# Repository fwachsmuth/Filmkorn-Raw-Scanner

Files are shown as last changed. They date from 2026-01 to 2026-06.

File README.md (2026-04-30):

# Filmkorn Raw-Scanner
## An affordable 12‑Bit 4K Motion Picture Film Scanner

Another DIY film scanner?  
Yes, but this one is different: the Filmkorn Raw Scanner is an open‑source project that enables digitizing small‑gauge films at breathtaking quality for a very low price. The project began in 2020 after a bet on the German [Filmvorführerforum](https://www.filmvorfuehrer.de/topic/31851-challenge-framescanner-f%C3%BCr-350%E2%82%AC-bauen/), when the infamous but similarly priced “Wolverine” film scanner from China (aka Somikon, aka Winait, aka Kodak, aka Hammacher‑Schlemmer) turned out to be an irredeemable film‑scratching disaster: Is it even possible to build a truly high‑quality scanner for under €500?

Yes, it is. Now anyone can build a scanner that digitizes their films gently and in fantastic quality.

## Introduction Video
Filmkorn Raw Scanner – demo video (https://www.youtube.com/watch?v=_LFE7quf9N0)

*(Click to play on Youtube)*

## Links
- You find extensive documentation on the [Project Wiki](https://github.com/fwachsmuth/Filmkorn-Raw-Scanner/wiki) (English and German)
- [Example Demo Video](https://www.youtube.com/watch?v=y674Rku_erA) (compressed, since Youtube)
- [Shop 🛒](https://lectronz.com/products/filmkorn-scanner-controller-board) to get a ready-made and populated Controller PCB and optionally some special accessories
- The latest [Image file](https://github.com/fwachsmuth/Filmkorn-Raw-Scanner/releases) for the Raspberry Pi
- Got your Scanner? [Getting Started](https://github.com/fwachsmuth/Filmkorn-Raw-Scanner/wiki/3.-User-Guide-EN)

**Special offer: Send me detailed photos and a description of converting another projector (Bauer, Eumig, whatever) for publication on this page, and I’ll refund the cost of the Scan‑Controller on request!**

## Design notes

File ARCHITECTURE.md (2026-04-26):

# Architecture

## System Roles

### Raspberry Pi — Camera and Brain

The Raspi is the central coordinator. It runs `scanner.py`, a Python application that:

- Controls the Pi HQ Camera (IMX477) via **picamera2**, capturing 12-bit DNG raw frames at up to 4K (4056×3040) or 2K (2028×1520).
- Drives an **HDMI overlay UI** (PIL/ImageDraw rendered to DRM framebuffer via tty1) for live preview and status display.
- Communicates with the Controller PCB via **I2C** (bus 1, address 0x2A), and polling it during scanning.
- Manages **file sync**: captured frames land in a RAM disk (`/mnt/ramdisk`), from which lsyncd moves them to the host Mac over Ethernet or to a local USB drive.
- Handles **OTA firmware updates**, SSH pairing, WiFi captive portal for network setup, and sleep/wake power management.

### Controller PCB — Hardware Interface

The PCB is built around an **ATmega328P** (Pretty much an Arduino Pro Mini at 3.3V and 8 MHz). It owns everything physical:

- **Film transport motor** — PWM-driven forward/reverse with a calibrated minimum duty cycle to guarantee movement from rest.
- **Eye sensor** (IR on GPIO2) — watches the main shaft and detectes a finished revolution via hardware interrupt (`stopMotorISR`). The ISR stops the motor and sets `CMD_SHOOT_RAW` for the next I2C poll from the Pi.
- **Film-end sensor** (GPIO3) — detects when the film strip runs out and stops scanning.
- **Lamp and fan** control (GPIO9, GPIO8).
- **Buttons and potentiometers** (analog pins A0–A3, A6) — navigation buttons, step/continuous speed knobs, exposure pot.
- **Board revision detection** (A7) — voltage divider that identifies PCB revision at runtime.

The firmware acts as an I2C slave. The Pi polls it; the controller queues one command at a time in `nextPiCmd` and returns it on the next `Wire.onRequest()` call.

### Host Computer — Optional Storage (macOS)

The host Mac is entirely optional. When paired over Ethernet:

- Receives DNG files from the Raspi in real time via **lsyncd + rsync** (rsync 3.x, SSH over eth0 only).
- Source files on the RAM disk are deleted after a successful transfer (`--remove-source-files`), keeping RAM usage flat.
- Hosts the **pairing scripts** (`host-computer/`) that establish SSH trust, configure file sync paths, and install the Remote Login prerequisite.

Without a paired host, scans go to a USB drive mounted at `/mnt/usb`.

---

## systemd Services

| Service | Type | Role |
|---|---|---|
| `filmkorn-ramdisk` | oneshot | Creates and mounts the RAM disk at `/mnt/ramdisk`; must be running before the scanner starts |
| `filmkorn-scanner` | simple | Main Python application — camera, I2C, UI, file routing. Restarts on failure. Requires `filmkorn-ramdisk` |
| `filmkorn-lsyncd` | simple | Runs lsyncd to sync `/mnt/ramdisk/` → host Mac (net) or `/mnt/usb/` (local). Config symlinked via `lsyncd.active.conf` |
| `filmkorn-firstboot` | oneshot | One-time setup on first boot: SSH host key generation, swap config, rootfs expansion |
| `filmkorn-sleep` | oneshot | Triggered by scanner.py to power down non-essential hardware for idle sleep |
| `filmkorn-wake` | oneshot | Triggered on wake to restore hardware state |
| `filmkorn-otp-schedule` | oneshot | Sets a timer to revoke the WiFi pairing OTP after its expiry window |
| `usb-mount-largest@` | oneshot | Udev-triggered: mounts the largest partition of a plugged-in USB drive to `/mnt/usb` |
| `usb-umount@` | oneshot | Udev-triggered: unmounts and syncs the USB drive on removal |

---

## Scanning Flow

```mermaid
sequenceDiagram
    participant User
    participant Controller as Controller PCB<br/>(ATmega328P)
    participant Pi as Raspberry Pi<br/>(scanner.py)
    participant Cam as Pi HQ Camera<br/>(picamera2)
    participant Disk as Storage<br/>(RAM disk → host/USB)

    User->>Controller: Press SCAN button
    Controller->>Pi: I2C poll → CMD_START_SCAN
    Pi->>Pi: Check storage available
    Pi->>Controller: I2C → CMD_READY
    Controller->>Controller: Enable lamp + fan

    loop For each frame
        Controller->>Controller: motorFWD1()<br/>advance film one frame
        Note over Controller: Eye sensor (IR) fires<br/>stopMotorISR() on FALLING edge
        Controller->>Controller: Stop motor<br/>nextPiCmd = CMD_SHOOT_RAW
        Controller->>Pi: I2C poll → CMD_SHOOT_RAW
        Pi->>Cam: Drain stale buffered frames<br/>(transport-era frames)
        Cam->>Pi: Capture DNG (12-bit raw)
        Pi->>Disk: Write DNG to /mnt/ramdisk/
        Pi->>Controller: I2C → CMD_READY
    end

    Note over Disk: lsyncd watches /mnt/ramdisk/<br/>rsync to host or USB<br/>deletes source after transfer

    alt Film end detected
        Controller->>Controller: Film-end sensor triggers<br/>stop scanning
        Controller->>Pi: I2C poll → CMD_STOP_SCAN
        Pi->>Pi: Wait for RAM disk to drain<br/>then show idle screen
    else User stops
        User->>Controller: Press STOP
        Controller->>Pi: I2C poll → CMD_STOP_SCAN
    end
```

### Key timing detail

The camera runs continuously in a ring buffer (`buffer_count=4`). When `CMD_SHOOT_RAW` arrives, the film has just stopped but the buffer still holds frames captured while it was moving ("transport-era frames"). `scanner.py` discards these before saving — using either a frame-count strategy (fast shutters) or a fixed settle + shutter-duration wait (slow shutters > 1/100 s). A user-adjustable "capture latency" setting controls how many additional frames are discarded as a safety margin.

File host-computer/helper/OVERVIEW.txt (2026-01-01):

        Host Computer                                   Raspberry Pi

┌──────────────────────────────────────┐
│ install_remote_scanning.sh           │
│ - installs Homebrew + rsync          │
│ - enables Remote Login               │
│ - touches .scanner_installed         │
└──────────────────┬───────────────────┘
                   │
                   ▼
┌──────────────────────────────────────┐
│ helper/pair.sh                       │
│ - creates and installs an ssh key    │
│ - configures raspi keys              │          ┌────────────────────────────────┐
│ - ensures destination path is set    ├─────────►│ pairing/update-destination.sh  │
└──────────────────────────────────────┘  calls   │ (via pair.sh)                  │
                   │                              │ - creates lsyncd-to-host.conf  │
                   │ if no scan                   │ - writes .scan_destination     │
                   │ destination                  │ - validates host/path/rsync    │
                   │ defined yet                  └────────────────────────────────┘
                   │
                   ▼
┌──────────────────────────────────────┐          ┌────────────────────────────────┐
│ helper/set_scan_destination.sh       │          │ pairing/update-destination.sh  │
│ - updates local .scan_destination    ├─────────►│ (via set_scan_destination.sh)  │
│ - calls update-destination           │  calls   │ - creates lsyncd-to-host.conf  │
└──────────────────────────────────────┘          │ - writes .scan_destination     │
                                                  │ - validates host/path/rsync    │
                                                  └────────────────────────────────┘

┌──────────────────────────────────────┐          ┌────────────────────────────────┐
│ helper/unpair.sh                     │          │ pairing/unpair-from-client.sh  │
│ - removes ssh keys and allowances    ├─────────►│ - removes ssh keys and         │
│                                      │  calls   │   makes the host computer      │
└──────────────────────────────────────┘          │   unknown                      │
                                                  └────────────────────────────────┘

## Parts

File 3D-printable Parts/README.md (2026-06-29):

## (Optional) 3D parts for lucky owners of a 3D printer

This directory contains some 3D printable parts for convenience and beauty, contributed by others. Thanks a ton for this, feel free to send any other parts you might create (or just raise a PR).

### Noris specific parts

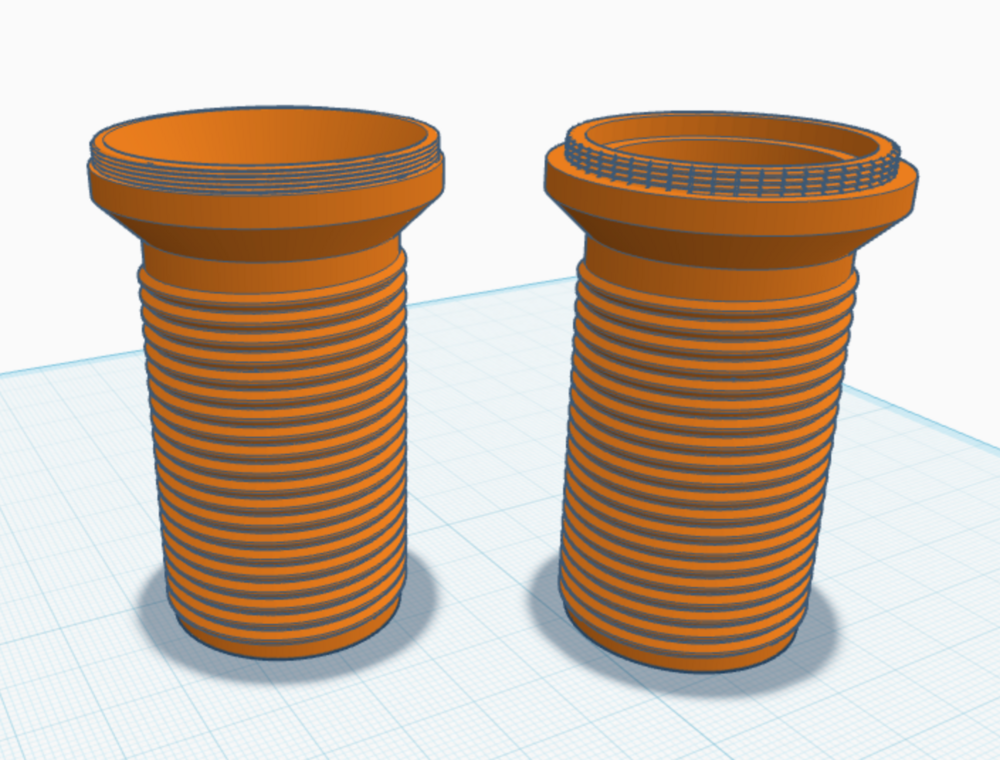
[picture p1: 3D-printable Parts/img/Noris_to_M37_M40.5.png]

These tubes fit right into the Noris Lens holder and make destroying the original lense obsolete. Their other end can be screwed into a Nikor enlarger lens (or any other lens with a M37 resp M40.5 fiilter hodler resp. adapter)

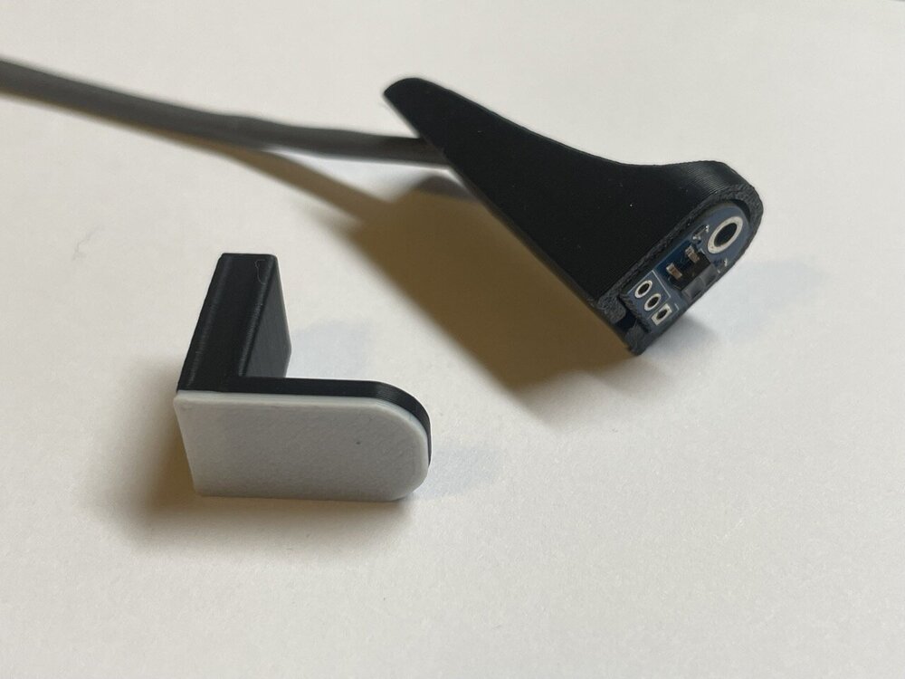
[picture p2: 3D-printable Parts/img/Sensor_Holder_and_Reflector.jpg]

These parts simplify mounting the film end detector on the projector. 

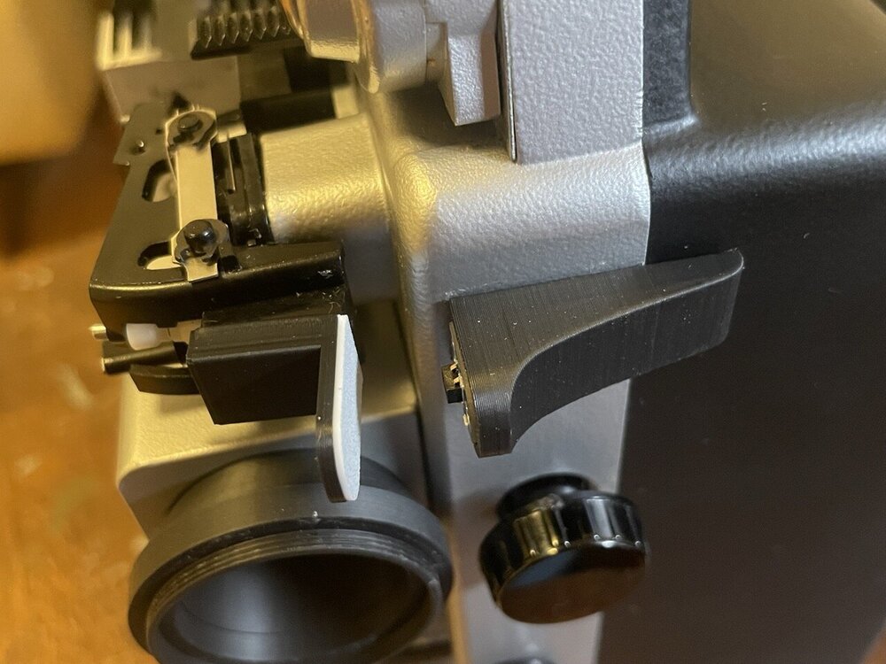
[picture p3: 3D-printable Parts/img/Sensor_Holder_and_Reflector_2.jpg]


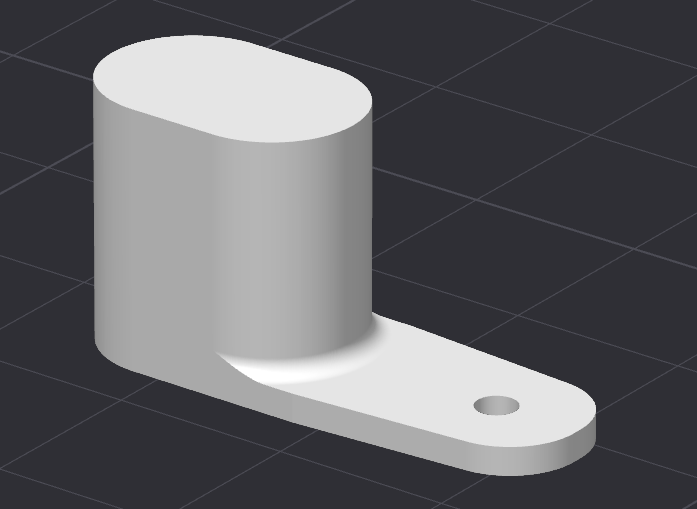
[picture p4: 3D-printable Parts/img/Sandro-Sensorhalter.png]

Holder for the motor shaft sensor. The Fusion file contains parameters that can be adjusted as desired to customize the holder. For example, the length of the holding arm or the spacer. Smoothing the top layer when printing is recommended, this ensures that the spacer fits nicely.

### Macro Focus Unit

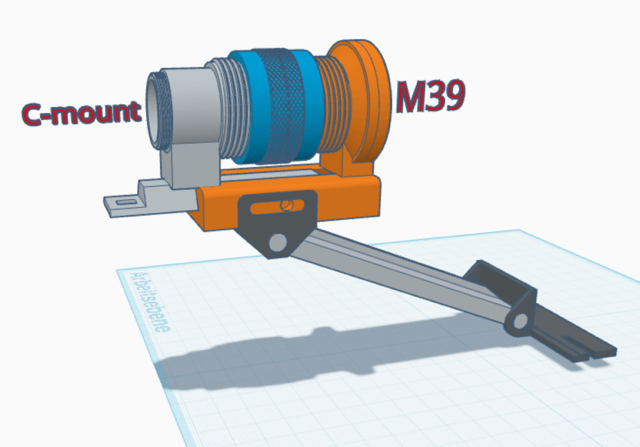
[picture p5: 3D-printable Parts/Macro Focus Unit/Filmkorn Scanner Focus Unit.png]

Sebastian wrote: 

_"Since I wanted the setup to be as portable as possible, I decided not to use a base plate for the scanner. So I needed a solution for focusing and a support to prevent mechanical vibrations from being transmitted to the camera._

_For focusing, I decided to cut the tube (or macro tube) that sits between the M39 mount and the camera, add a reverse thread to it, and connect both parts so they can slide along a carriage. A threaded adapter sleeve allows for very precise focusing._

_To prevent wobbling, the entire assembly is supported diagonally against the housing. At the upper end of the support, beneath the focusing unit, there is a movable slide, allowing the camera’s vertical axis to be finely adjusted by applying more or less upward pressure. The camera is screwed onto the back."_

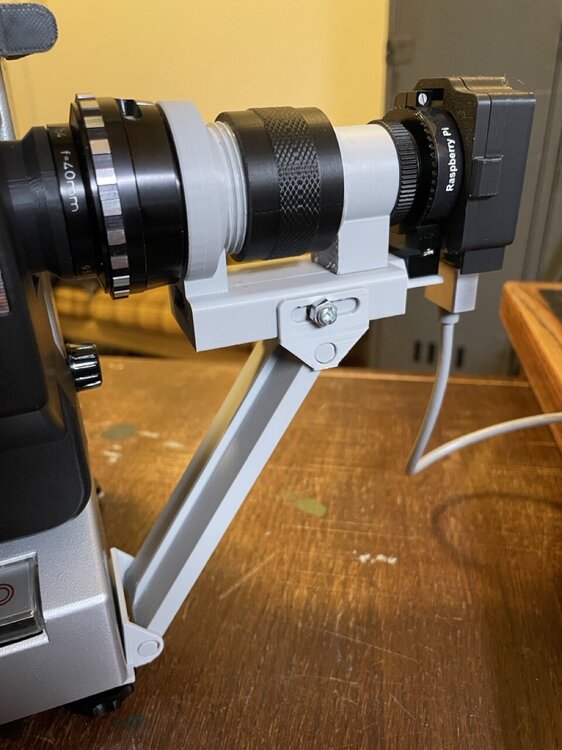
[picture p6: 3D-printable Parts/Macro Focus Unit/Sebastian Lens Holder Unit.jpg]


### Lens Holder for 42.5 mm Diameter 16 mm Projectors

Thsi simple tube screws into a 40.5mm enlarger lens filter holder and just snugs into the 42.4 (42.5) mm lens mount of common 16 mm projectors.

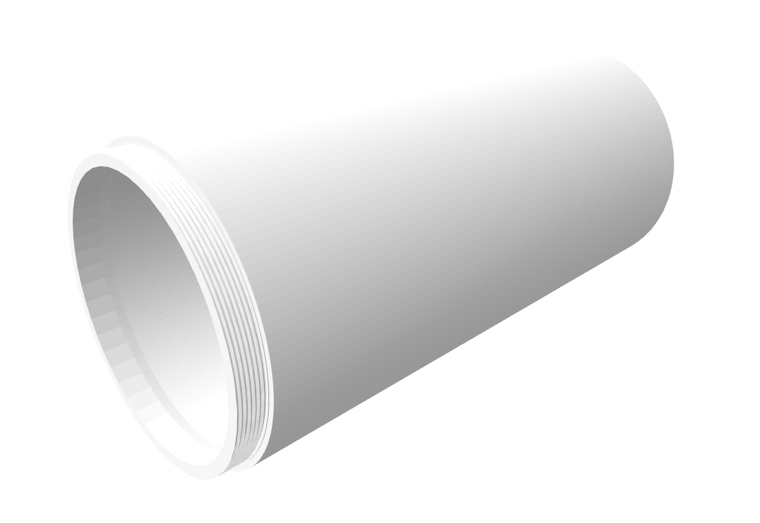
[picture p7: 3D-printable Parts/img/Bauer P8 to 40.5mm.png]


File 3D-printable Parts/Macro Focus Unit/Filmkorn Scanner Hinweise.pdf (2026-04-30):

Hinweise zur M39 auf Raspberry Pi HQ Kamera Macro Fokus-Einheit:

- Part 1 und 2 müssen aufrecht gedruckt werden wegen der Gewinde. Bitte mit “Snug”-Support drucken (Wie in dem beigefügten Slice Screenshot zu sehen
- Part 2 gibt es in zwei Versionen. Die erste Version ist an der C-mont Seite etwas kürzer. Ich habe dort einen C-Mount Makro Zwischenring aus Metall installiert, damit das C-mount-Gewinde der Raspi HQ Kamera einfacher anzuschrauben ist.
Die Datei mit der Endung “Part 2A” ist dafür gedacht, wenn man keinen Macro Zwischenring besitzt und die HQ Kamera direkt auf das Plastikgewinde schrauben möchte.
- damit die Fokus-Einheit nicht wackelt, sind die Toleranzen von Part 1 und 2 sehr eng gehalten. Wenn die beiden Teile sich nicht geschmeidig ineinanderschieben und bewegen lassen, bitte ein wenig mit einer Feile / Sandpapier nachschleifen.
- Beim Zusammenbau beide Teile soweit ineinander schieben, dass der Überwurfring gerade noch zwischen die Gewinde beider Teile 1 und 2 passt. Dann beide Teile weiter soweit aufeinander zu schieben, bis der Ring von alleine zwischen den Gewinden hält und ihn dann gegen den Uhrzeigersinn drehen. Die Gewinde sollten jetzt alle ineinander greifen und die Schlitten sollte sich aufeinander zu bewegen.
Darüber kann man nun den Abstand von Kamera und Film (und somit den Fokus) ziemlich präzise einstellen
- Für die Stütze benötigt man 4mm Einschmelzgewinde und entsprechend 2 Feststellschrauben

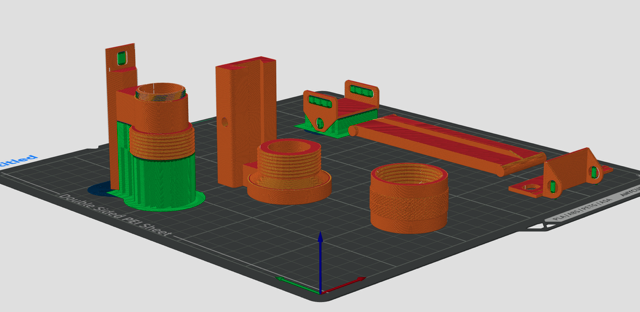
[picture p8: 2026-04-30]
3D-printable Parts/Macro Focus Unit/Filmkorn Scanner Focus Unit Snug Support.png

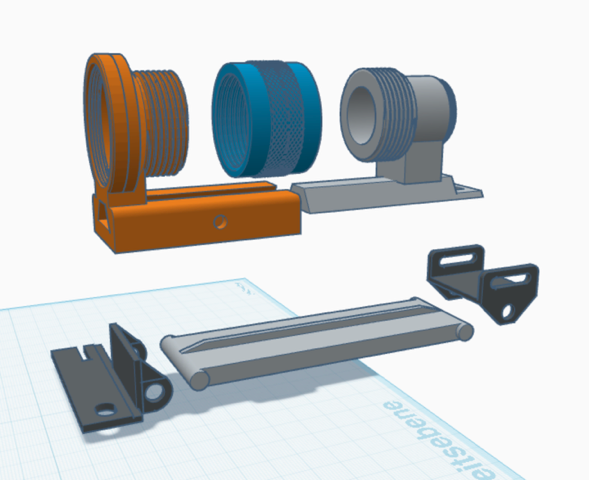
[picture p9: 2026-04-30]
3D-printable Parts/Macro Focus Unit/Filmkorn Scanner Focus Unit Einzelteile.png

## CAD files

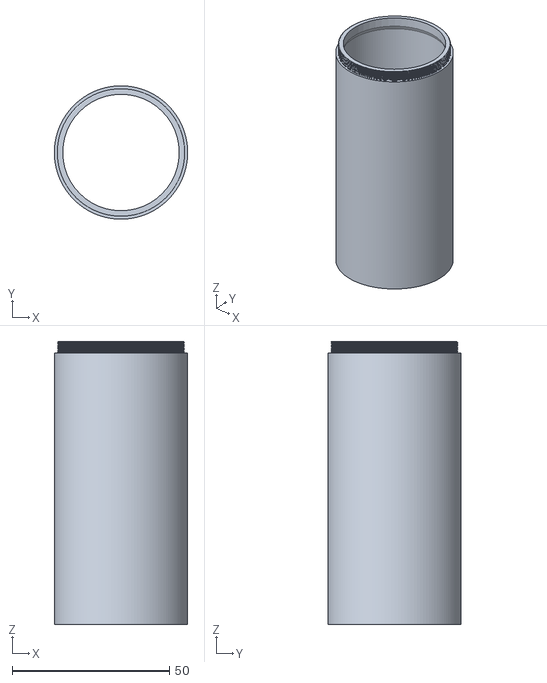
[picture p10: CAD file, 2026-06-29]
3D-printable Parts/Bauer P8 to M40.5.stl
42.4 x 42.4 x 90.0

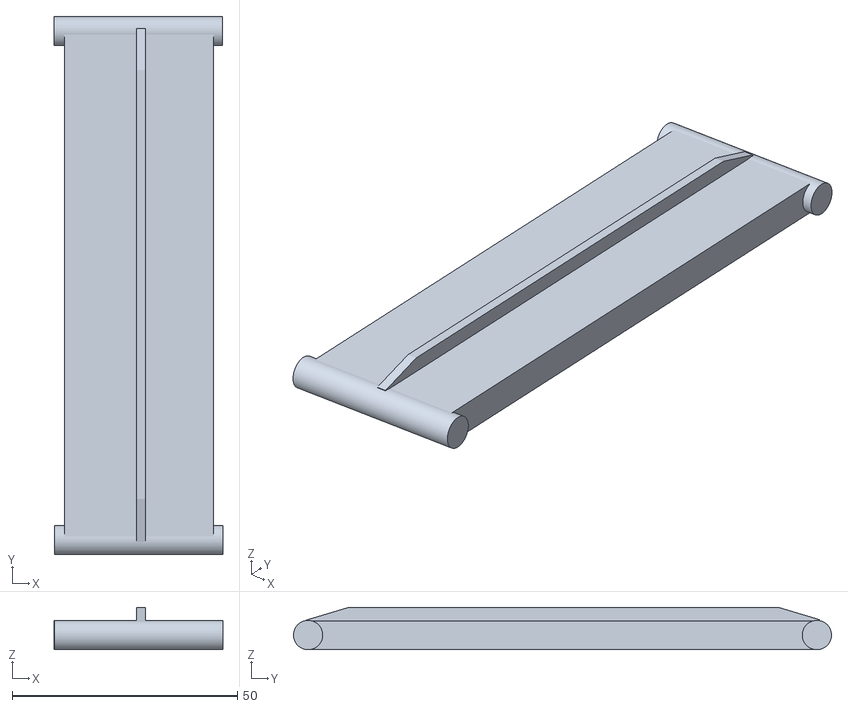
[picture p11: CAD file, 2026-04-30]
3D-printable Parts/Macro Focus Unit/Filmkorn Scanner M39 Macro Focus unit part 5.stl
37.5 x 119.4 x 9.40

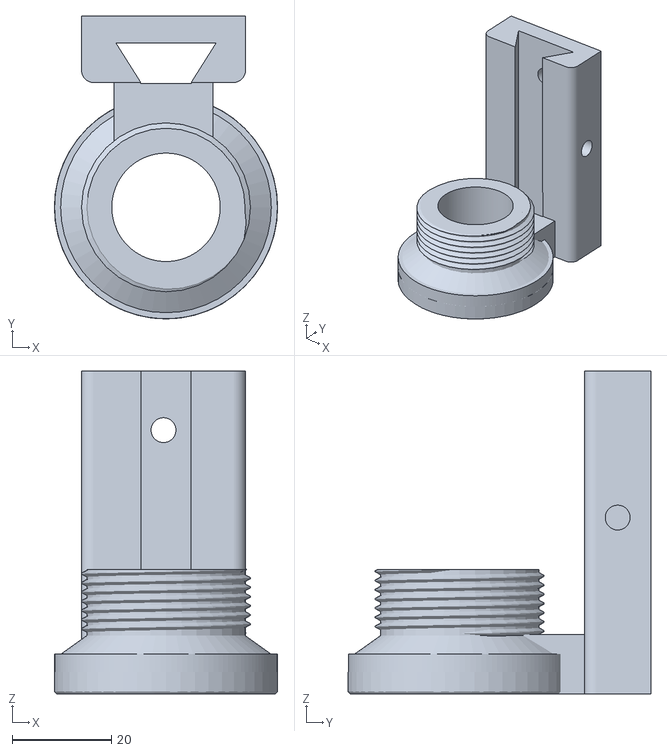
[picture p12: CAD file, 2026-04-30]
3D-printable Parts/Macro Focus Unit/Filmkorn Scanner M39 Macro Focus unit part 1.stl
44.9 x 61.0 x 65.0

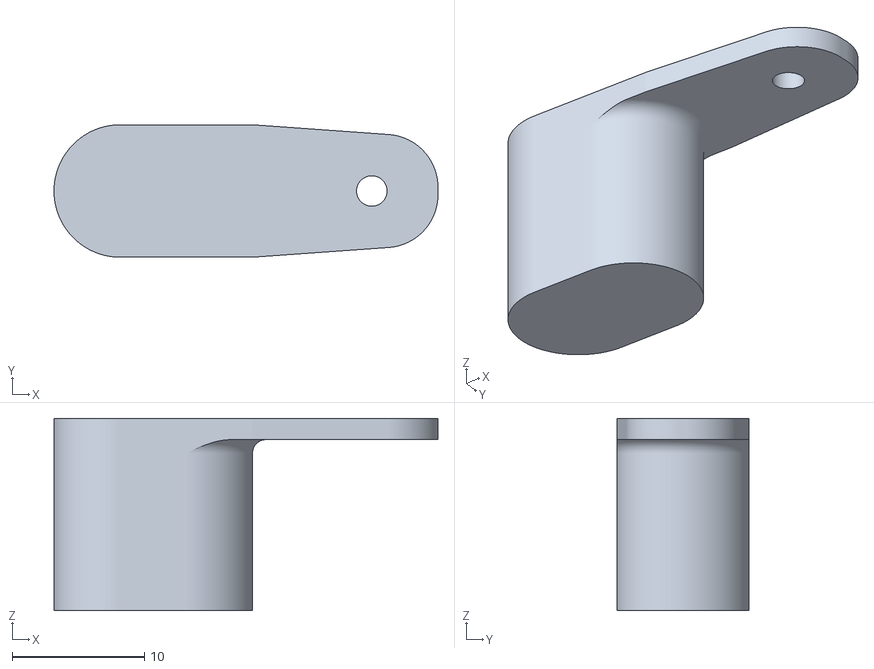
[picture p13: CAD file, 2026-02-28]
3D-printable Parts/Shaft_ Sensor_Holder_Noris.stl
29.0 x 10.0 x 14.5

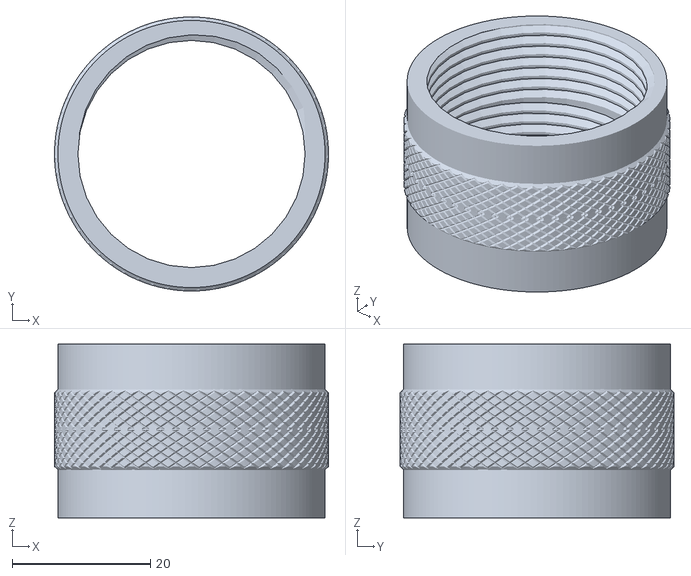
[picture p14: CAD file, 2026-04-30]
3D-printable Parts/Macro Focus Unit/Filmkorn Scanner M39 Macro Focus unit part 3.stl
39.6 x 39.6 x 25.1

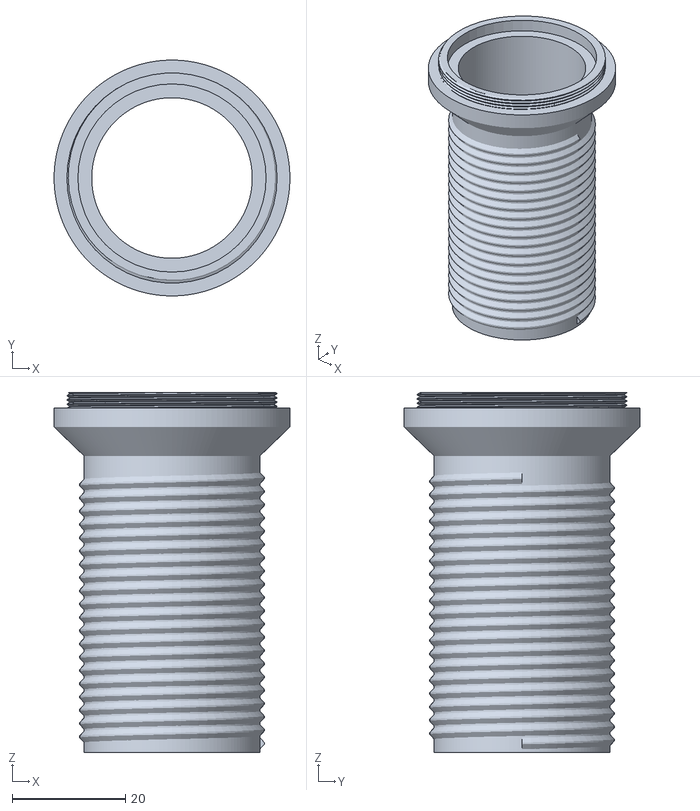
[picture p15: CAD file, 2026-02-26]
3D-printable Parts/Noris to M37 Adapter threaded.stl
41.6 x 41.6 x 63.5

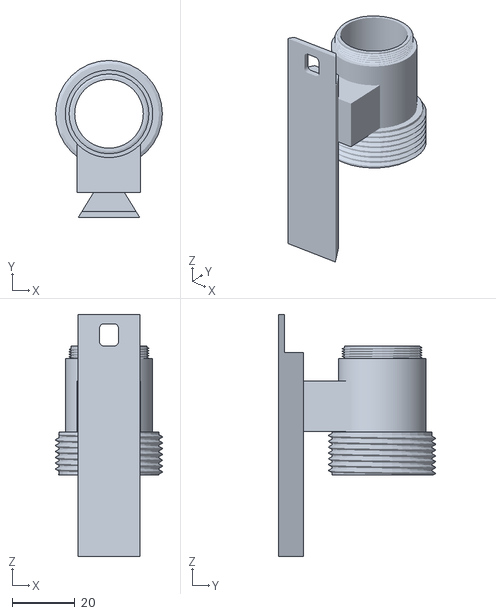
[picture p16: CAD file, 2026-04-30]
3D-printable Parts/Macro Focus Unit/Filmkorn Scanner M39 Macro Focus unit part 2A.stl
34.0 x 50.0 x 77.0

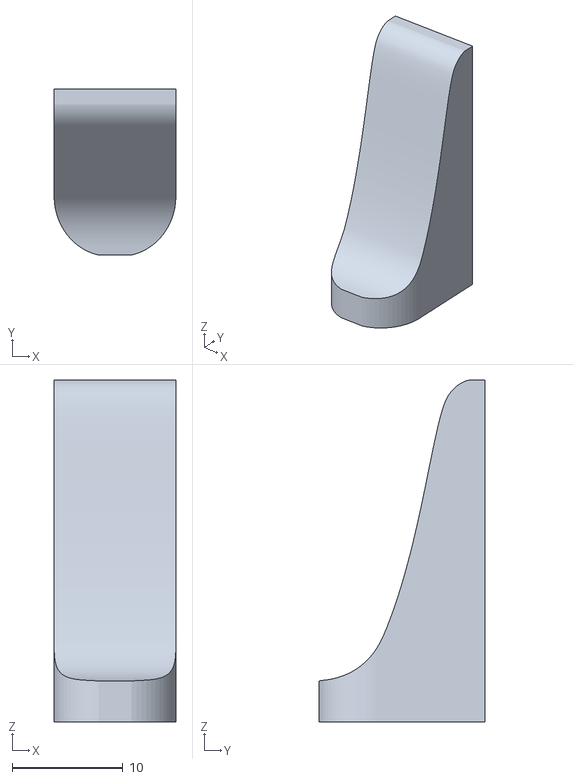
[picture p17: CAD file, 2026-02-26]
3D-printable Parts/Noris Scanner end sensor holder.stl
11.0 x 15.0 x 30.9

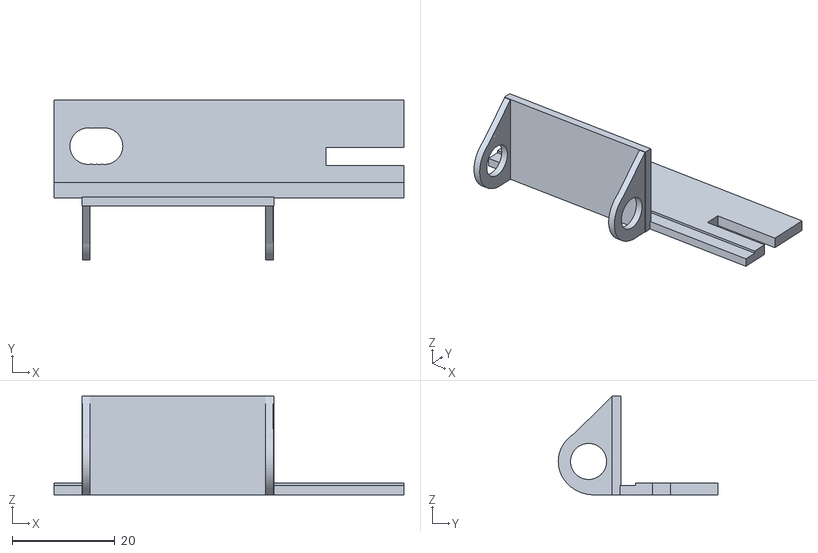
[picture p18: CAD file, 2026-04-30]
3D-printable Parts/Macro Focus Unit/Filmkorn Scanner M39 Macro Focus unit part 6.stl
68.0 x 31.0 x 19.2

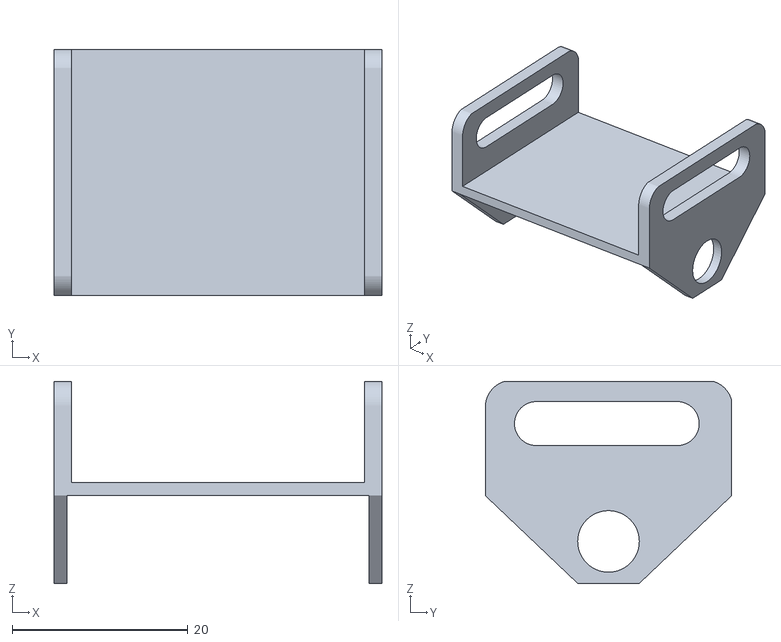
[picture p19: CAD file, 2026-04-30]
3D-printable Parts/Macro Focus Unit/Filmkorn Scanner M39 Macro Focus unit part 4.stl
37.3 x 28.0 x 23.0

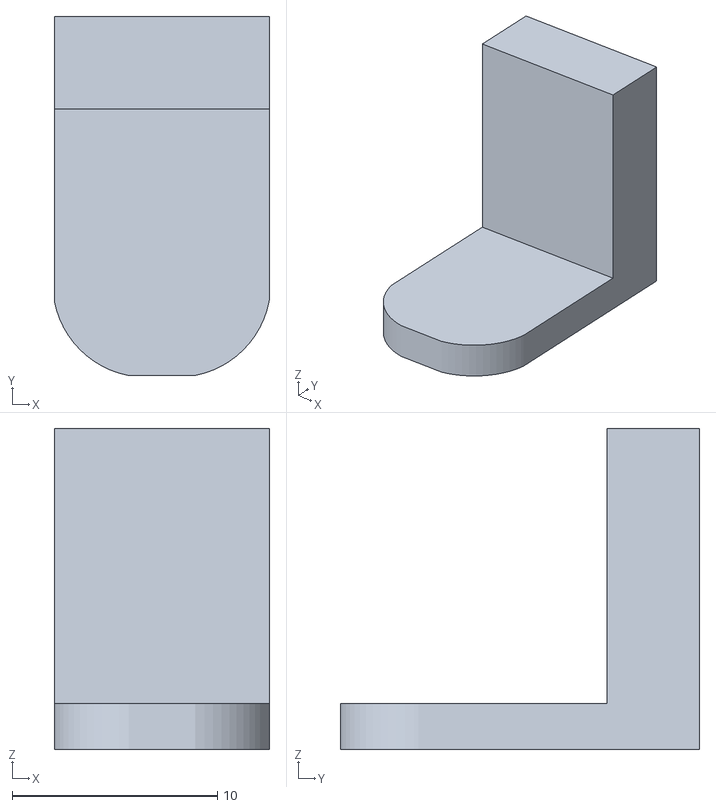
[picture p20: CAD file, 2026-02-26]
3D-printable Parts/Noris Scanner end-sensor-reflector.stl
10.5 x 17.5 x 15.6

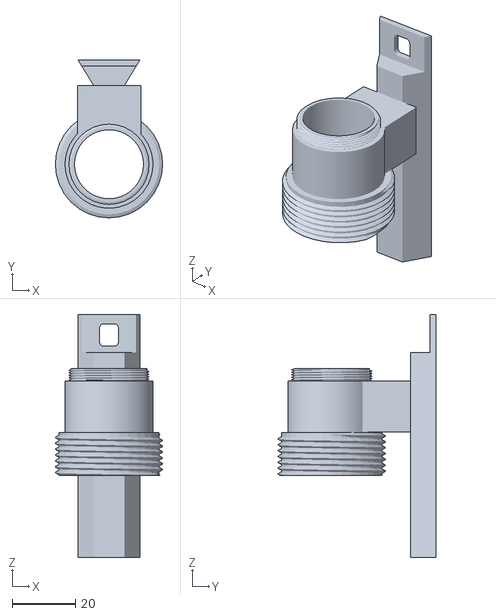
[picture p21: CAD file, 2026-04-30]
3D-printable Parts/Macro Focus Unit/Filmkorn Scanner M39 Macro Focus unit part 2.stl
34.0 x 50.0 x 77.0

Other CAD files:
3D-printable Parts/Noris to M40.5 Adapter threaded.stl
3D-printable Parts/Shaft_Sensor_Holder_Noris.f3d

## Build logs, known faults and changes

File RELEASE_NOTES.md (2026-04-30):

# Filmkorn Raw Scanner — Release Notes v1.0.0

_Released April 26, 2026_

---

## What's New

### DaVinci Resolve Project Presets

Some DaVinci Resolve project settings presets for 18/24 fps and 2K/4K are now bundled with the scanner and automatically placed on the connected USB drive. Import them directly to your Resolve Project Manager to get a solid starting point for color grading your scans — no manual configuration needed.

### Resources and 3D Parts on USB Drive

The community 3D-printable parts and DaVinci Resolve assets are now automatically copied to your USB drive whenever it is connected. This makes them accessible directly from the drive without having to visit the repository or dig into installation directories.

### Pairing App Auto-Update

The pairing app on the USB drive is now automatically kept up to date. If an older version is detected, it is replaced with the current one at pairing time — no manual downloads required.

### Board Revision Detection

The scanner now detects which hardware revision of the controller board is installed and adapts its behavior accordingly. Rev E+ boards correctly handle GPIO5 as the Target Switch, which was previously mislabeled. This also lays the groundwork for transparent support of future board revisions.

---

## Bug Fixes & Reliability Improvements

### FPS Display Accuracy

Fixed a calculation error in the frames-per-second readout on the HUD. The displayed value now correctly reflects the actual scanning rate.

### Hostname Cleanup on Unpairing

Fixed an issue where stale hostname entries could remain after unpairing the scanner, which could cause confusing behavior on subsequent pairing attempts.

---

# Filmkorn Raw Scanner — Release Notes v0.9.9

_Released March 8, 2026_

---

## What's New

### More Languages

The scanner UI is now also available in **French**, **Spanish**, and **Italian** — in addition to the existing English and German. The language can be selected from the Settings menu (long press on STOP button)

### Flexible Film End Sensor configurations

The film-end sensor can now be configured to match your hardware. A new **Film End Sensor** setting in the Settings menu offers three modes:

- **Normal** — the default, for standard active-low sensors, as the one coming with the controller
- **Inverted** — for sensors that signal the opposite polarity (like some fork sensors)
- **None** — disables end-of-film detection entirely, useful when no sensor is installed. You need to stop the projector manually once the scan is complete, otherwise your hard drive will fill up quickly with blank frames!

### Pairing Menu Timeout

The Bluetooth pairing screen now exits automatically after a timeout instead of waiting indefinitely. If no device pairs within the window, the scanner returns to the main menu on its own — no more getting stuck on the pairing screen after an accidental button press.

### Scan-Idle Watchdog

A new watchdog monitors for situations where the scanner appears to be running but no frames are advancing — typically caused by a rare I²C communication jam between the Raspberry Pi and the scan controller. When detected, the scanner now recovers automatically instead of hanging silently mid-roll.

---

## Bug Fixes & Reliability Improvements

### Firmware Update Menu Exit

Fixed a bug where the firmware update submenu could not be exited cleanly, leaving the scanner unresponsive until restarted.

### Settings Menu Polish

Labels, layout, and spacing across all settings screens have been cleaned up and made consistent. The menus now look and feel uniform regardless of which language is selected.

---

# Filmkorn Raw Scanner — Release Notes v0.9.8

_Released March 6, 2026_

---

## What's New

### Motor Calibration

The scanner can now calibrate itself to your specific projector motor. Open the **Settings menu** and choose **Calibrate Motor** — the scanner will run through its speed range once and find the exact minimum power level needed to keep film transport always going reliably.

### Adjustable Capture Latency

A new **Capture Latency** setting in the Settings menu lets you tune how many camera-frames (not film frames!) are discarded after the motor stops before the image is captured. The default (1 frame) works well for most setups, but you can dial it up if you're occasionally getting slightly blurry, jello- or motion-affected frames, or dial it down if you want maximum speed. Note that a _slower_ (mid-range) stepping speed is often beneficial for the film to settle quickly after tranport, then potentially allowing a lower cpature latency, scanning effectively slightly faster. :) 

### Settings Survive Re-imaging

All your settings — pairing configuration, Wi-Fi networks, language, capture latency, and motor calibration — are now automatically backed up to the scan controller itself. If you ever need to re-flash the Raspberry Pi, your settings are restored from the controller without you having to reconfigure anything.

### Community 3D-Printable Parts

A new [`3d-parts/`](3d-parts/) folder has been added to the repository, containing printable STL files contributed by the community:

- **Noris lens adapters** (M37 and M40.5 threads) — lets you mount enlarger lenses on a Noris projector without modifying the original lens; contributed by Sebastian
- **Parametric motor shaft sensor holder** (includes Fusion 360 source) — adjustable arm length and spacer; contributed by Sandro
- **Film end sensor holder and reflector** — makes mounting the end-of-film detector much easier

---

## Bug Fixes & Reliability Improvements

### Frame Capture Reliability
The core capture logic was significantly overhauled. The scanner now uses the camera's internal sensor  timestamps to guarantee frames are pulled from the buffer in the correct order, and actively discards any stale frames that accumulated while the motor was running. This fixes rare cases where an out-of-order or motion-blurred frame could slip through during long scans.

### Settings Menu Was Sometimes Unreachable
Fixed a communication issue between the Raspberry Pi and the scan controller that could make the Settings menu unresponsive. 

### OTA Updater Permission Fix
Fixed a (final?) bug in the over-the-air update mechanism that caused incorrect file permissions after an update, which could prevent subsequent updates from working. This is more complicated than I anticipated :)

### Disk-Full Handling
Fixed a race condition where filling up the disk mid-scan could cause the scanner to hang rather than stopping cleanly.

### Update Check Fix
Fixed an issue where the version update check could fail silently on systems using developer keys.

### First Frame preserved
Occasionally, the first scanned frame was dropped. Now no more!

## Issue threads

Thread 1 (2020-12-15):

convert.py fails to create new folder after 10,000 images

fwachsmuth, 2020-12-15:
`python3 convert.py -i /Volumes/Daten/Movies/_piscan/raw-intermediates/ --cinema-dng --compress --keep-running` eventually fails with below Console output, since the new destination folder 000100 has not been created:

```
/Volumes/Daten/Movies/_piscan/raw-intermediates/2020-12-15T12_16_00/09699.jpg converted to /Volumes/Daten/Movies/_piscan/DNGs/2020-12-15T12_16_00/CONTENTS/IMAGE/000000/2020-12-15T12_16_00_9998.dng
/Volumes/Daten/Movies/_piscan/raw-intermediates/2020-12-15T12_16_00/09700.jpg converted to /Volumes/Daten/Movies/_piscan/DNGs/2020-12-15T12_16_00/CONTENTS/IMAGE/000000/2020-12-15T12_16_00_9999.dng
Exception in thread Thread-1:
Traceback (most recent call last):
  File "/usr/local/Cellar/python@3.9/3.9.1/Frameworks/Python.framework/Versions/3.9/lib/python3.9/threading.py", line 954, in _bootstrap_inner
    self.run()
  File "/Users/peaceman/code/Arduino/Piscanuino/watchdog/src/watchdog/observers/api.py", line 199, in run
    self.dispatch_events(self.event_queue, self.timeout)
  File "/Users/peaceman/code/Arduino/Piscanuino/watchdog/src/watchdog/observers/api.py", line 372, in dispatch_events
    handler.dispatch(event)
  File "/Users/peaceman/code/Arduino/Piscanuino/watchdog/src/watchdog/events.py", line 261, in dispatch
    {
  File "/Users/peaceman/code/Arduino/Piscanuino/convert.py", line 109, in on_moved
    convert_new_raw(event.dest_path)
  File "/Users/peaceman/code/Arduino/Piscanuino/convert.py", line 100, in convert_new_raw
    convert_raw(
  File "/Users/peaceman/code/Arduino/Piscanuino/convert.py", line 156, in convert_raw
    open(dest_file, 'wb') as dng_file:
FileNotFoundError: [Errno 2] No such file or directory: '/Volumes/Daten/Movies/_piscan/DNGs/2020-12-15T12_16_00/CONTENTS/IMAGE/000100/2020-12-15T12_16_00_0000.dng'
```

Closed 2020-12-16.

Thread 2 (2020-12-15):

convert.py can't resume a conversion after it has been terminated

fwachsmuth, 2020-12-15:
When convert.py terminates for whatever reason, it can not resume processing a partial remainder of raw-intermediates, since their destination directory already exists — see log below.
It would be great if existing CinemaDNG directory structures could be anticipated.

```
FW-iMac-4K:Piscanuino peaceman$ python3 convert.py -i /Volumes/Daten/Movies/_piscan/raw-intermediates/ --cinema-dng --compress --keep-running
Traceback (most recent call last):
  File "/Users/peaceman/code/Arduino/Piscanuino/convert.py", line 205, in <module>
    observer = convert(**vars(args))
  File "/Users/peaceman/code/Arduino/Piscanuino/convert.py", line 118, in convert
    if convert_raw(
  File "/Users/peaceman/code/Arduino/Piscanuino/convert.py", line 141, in convert_raw
    cinema_dng_picture.reset(
  File "/Users/peaceman/code/Arduino/Piscanuino/convert.py", line 30, in __init__
    raise FileExistsError(
FileExistsError: CinemaDNG '/Volumes/Daten/Movies/_piscan/DNGs/2020-12-15T12_16_00' already exists
```

Closed 2020-12-16.

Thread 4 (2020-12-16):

piscan.py occasionally terminates with i2c failure

fwachsmuth, 2020-12-16:
```python
def tell_arduino(command: Command):
    arduino.write_byte(arduino_i2c_address, command.value)
```

sometimes fails (e.g. due to EMF) as below, breaking the scan process. A couple of silent retries would be beneficial.

```
[Errno 121] Remote I/O error
  File "/home/pi/code/Piscanuino/piscan.py", line 208, in tell_arduino
    arduino.write_byte(arduino_i2c_address, command.value)
  File "/home/pi/code/Piscanuino/piscan.py", line 224, in say_ready
    tell_arduino(Command.READY)
  File "/home/pi/code/Piscanuino/piscan.py", line 221, in shoot_raw
    say_ready()
  File "/home/pi/code/Piscanuino/piscan.py", line 205, in loop
    func()
  File "/home/pi/code/Piscanuino/piscan.py", line 188, in main
    loop()
  File "/home/pi/code/Piscanuino/piscan.py", line 234, in <module>
    main()
``

Closed 2020-12-16.

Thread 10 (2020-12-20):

Could not start new Project after stopping a Scan

fwachsmuth, 2020-12-20:
```
One raw taken (0.842s); Told Arduino we are ready
One raw taken (0.648s); Told Arduino we are ready
One raw taken (1.03s); Told Arduino we are ready
Nevermind; Stopped scanning
Lamp and camera preview disabled
Lamp and camera preview enabled
Remote I/O Error while trying to send Arduino command
Command numbers not in sync (Pi: 2; Arduino: 0)
Command numbers not in sync (Pi: 2; Arduino: 1)
Command numbers not in sync (Pi: 2; Arduino: 1)
Command numbers not in sync (Pi: 2; Arduino: 1)
Command numbers not in sync (Pi: 2; Arduino: 1)
...
Command numbers not in sync (Pi: 2; Arduino: 1)
Command numbers not in sync (Pi: 2; Arduino: 1)
Command numbers not in sync (Pi: 2; Arduino: 1)
Set raws path to /home/pi/Pictures/raw-intermediates/2020-12-20T17_34_21
Started scanning
One raw taken (0.797s); Told Arduino we are ready
Command numbers not in sync (Pi: 4; Arduino: 3)
Command numbers not in sync (Pi: 4; Arduino: 3)
Command numbers not in sync (Pi: 4; Arduino: 3)
Command numbers not in sync (Pi: 4; Arduino: 3)
```

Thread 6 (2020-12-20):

piscan.py fails to continue-at due to invalid Zoom Mode

fwachsmuth, 2020-12-20:
```
pi@piscan:~/code/Piscanuino $ /usr/bin/python3 /home/pi/code/Piscanuino/piscan.py --continue-at 624
Lamp and camera preview enabled
ValueError: 3 is not a valid ZoomMode

During handling of the above exception, another exception occurred:

Traceback (most recent call last):
  File "/home/pi/code/Piscanuino/piscan.py", line 336, in <module>
    loop()
  File "/home/pi/code/Piscanuino/piscan.py", line 211, in loop
    ask_arduino()
  File "/home/pi/code/Piscanuino/piscan.py", line 247, in ask_arduino
    state.from_byte(response)
  File "/home/pi/code/Piscanuino/piscan.py", line 172, in from_byte
    self.zoom_mode = ZoomMode((byte & 0x06) >> 1)
  File "/usr/lib/python3.7/enum.py", line 310, in __call__
    return cls.__new__(cls, value)
  File "/usr/lib/python3.7/enum.py", line 564, in __new__
    raise exc
  File "/usr/lib/python3.7/enum.py", line 548, in __new__
    result = cls._missing_(value)
  File "/usr/lib/python3.7/enum.py", line 577, in _missing_
    raise ValueError("%r is not a valid %s" % (value, cls.__name__))
ValueError: 3 is not a valid ZoomMode
```

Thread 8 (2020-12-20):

Scan hangs due to i2c commands chasing catch up

fwachsmuth, 2020-12-20:
```
One raw taken (0.739s); Told Arduino we are ready
One raw taken (0.747s); Told Arduino we are ready
One raw taken (1.19s); Told Arduino we are ready
One raw taken (0.71s); Told Arduino we are ready
Remote I/O Error while trying to send Arduino command
Command numbers not in sync (Pi: 8; Arduino: 0)
Command numbers not in sync (Pi: 8; Arduino: 1)
Command numbers not in sync (Pi: 8; Arduino: 2)
Command numbers not in sync (Pi: 8; Arduino: 3)
Command numbers not in sync (Pi: 8; Arduino: 4)
Command numbers not in sync (Pi: 8; Arduino: 5)
Command numbers not in sync (Pi: 8; Arduino: 6)
Command numbers not in sync (Pi: 8; Arduino: 7)
One raw taken (0.702s); Told Arduino we are ready
Command numbers not in sync (Pi: 10; Arduino: 9)
One raw taken (1.1s); Told Arduino we are ready
Command numbers not in sync (Pi: 12; Arduino: 11)
One raw taken (0.668s); Told Arduino we are ready
Command numbers not in sync (Pi: 14; Arduino: 13)
One raw taken (0.757s); Told Arduino we are ready
Command numbers not in sync (Pi: 0; Arduino: 15)
One raw taken (0.902s); Told Arduino we are ready
Command numbers not in sync (Pi: 2; Arduino: 1)
One raw taken (0.787s); Told Arduino we are ready
Command numbers not in sync (Pi: 4; Arduino: 3)
One raw taken (0.7s); Told Arduino we are ready
Command numbers not in sync (Pi: 6; Arduino: 5)
One raw taken (0.674s); Told Arduino we are ready
Command numbers not in sync (Pi: 8; Arduino: 7)
One raw taken (0.956s); Told Arduino we are ready
Command numbers not in sync (Pi: 10; Arduino: 9)
One raw taken (0.7s); Told Arduino we are ready
Command numbers not in sync (Pi: 12; Arduino: 11)
One raw taken (0.672s); Told Arduino we are ready
Command numbers not in sync (Pi: 14; Arduino: 13)
One raw taken (0.735s); Told Arduino we are ready
Command numbers not in sync (Pi: 0; Arduino: 15)
One raw taken (0.747s); Told Arduino we are ready
Command numbers not in sync (Pi: 2; Arduino: 1)
One raw taken (0.753s); Told Arduino we are ready
Command numbers not in sync (Pi: 4; Arduino: 3)
One raw taken (0.698s); Told Arduino we are ready
Command numbers not in sync (Pi: 6; Arduino: 5)
One raw taken (0.718s); Told Arduino we are ready
Command numbers not in sync (Pi: 8; Arduino: 7)
One raw taken (0.702s); Told Arduino we are ready
Command numbers not in sync (Pi: 10; Arduino: 9)
One raw taken (0.704s); Told Arduino we are ready
Command numbers not in sync (Pi: 12; Arduino: 11)
One raw taken (0.702s); Told Arduino we are ready
Command numbers not in sync (Pi: 14; Arduino: 13)
One raw taken (0.701s); Told Arduino we are ready
Command numbers not in sync (Pi: 0; Arduino: 15)
One raw taken (1.85s); Told Arduino we are ready
Command numbers not in sync (Pi: 2; Arduino: 1)
One raw taken (0.716s); Told Arduino we are ready
Command numbers not in sync (Pi: 4; Arduino: 3)
One raw taken (0.691s); Told Arduino we are ready
Command numbers not in sync (Pi: 6; Arduino: 5)
One raw taken (0.718s); Told Arduino we are ready
Command numbers not in sync (Pi: 8; Arduino: 7)
One raw taken (1.09s); Told Arduino we are ready
Command numbers not in sync (Pi: 10; Arduino: 9)
One raw taken (0.903s); Told Arduino we are ready
Command numbers not in sync (Pi: 12; Arduino: 11)
One raw taken (2.99s); Told Arduino we are ready
Command numbers not in sync (Pi: 14; Arduino: 13)
One raw taken (0.757s); Told Arduino we are ready
Command numbers not in sync (Pi: 0; Arduino: 15)
One raw taken (0.742s); Told Arduino we are ready
Command numbers not in sync (Pi: 2; Arduino: 1)
One raw taken (0.726s); Told Arduino we are ready
Command numbers not in sync (Pi: 4; Arduino: 3)
One raw taken (1.14s); Told Arduino we are ready
Command numbers not in sync (Pi: 6; Arduino: 5)
One raw taken (0.696s); Told Arduino we are ready
Command numbers not in sync (Pi: 8; Arduino: 7)
One raw taken (0.688s); Told Arduino we are ready
Command numbers not in sync (Pi: 10; Arduino: 9)
One raw taken (0.737s); Told Arduino we are ready
Command numbers not in sync (Pi: 12; Arduino: 11)
One raw taken (0.703s); Told Arduino we are ready
Command numbers not in sync (Pi: 14; Arduino: 13)
One raw taken (0.676s); Told Arduino we are ready
Command numbers not in sync (Pi: 0; Arduino: 15)
One raw taken (1.3s); Told Arduino we are ready
Command numbers not in sync (Pi: 2; Arduino: 1)
One raw taken (0.71s); Told Arduino we are ready
Command numbers not in sync (Pi: 4; Arduino: 3)
One raw taken (0.702s); Told Arduino we are ready
Command numbers not in sync (Pi: 6; Arduino: 5)
One raw taken (0.677s); Told Arduino we are ready
Command numbers not in sync (Pi: 8; Arduino: 7)
One raw taken (0.763s); Told Arduino we are ready
Command numbers not in sync (Pi: 10; Arduino: 9)
One raw taken (0.835s); Told Arduino we are ready
Command numbers not in sync (Pi: 12; Arduino: 11)
One raw taken (1.23s); Told Arduino we are ready
Command numbers not in sync (Pi: 14; Arduino: 13)
One raw taken (0.703s); Told Arduino we are ready
Command numbers not in sync (Pi: 0; Arduino: 15)
One raw taken (0.703s); Told Arduino we are ready
Command numbers not in sync (Pi: 2; Arduino: 1)
One raw taken (0.66s); Told Arduino we are ready
Command numbers not in sync (Pi: 4; Arduino: 3)
One raw taken (0.924s); Told Arduino we are ready
Command numbers not in sync (Pi: 6; Arduino: 5)
One raw taken (0.76s); Told Arduino we are ready
Command numbers not in sync (Pi: 8; Arduino: 7)
One raw taken (1.33s); Told Arduino we are ready
Command numbers not in sync (Pi: 10; Arduino: 9)
One raw taken (0.71s); Told Arduino we are ready
Command numbers not in sync (Pi: 12; Arduino: 11)
One raw taken (0.732s); Told Arduino we are ready
Command numbers not in sync (Pi: 14; Arduino: 13)
One raw taken (0.906s); Told Arduino we are ready
Command numbers not in sync (Pi: 0; Arduino: 15)
One raw taken (0.7s); Told Arduino we are ready
Command numbers not in sync (Pi: 2; Arduino: 1)
One raw taken (0.736s); Told Arduino we are ready
Command numbers not in sync (Pi: 4; Arduino: 3)
One raw taken (1.3s); Told Arduino we are ready
Command numbers not in sync (Pi: 6; Arduino: 5)
One raw taken (0.723s); Told Arduino we are ready
Command numbers not in sync (Pi: 8; Arduino: 7)
One raw taken (0.684s); Told Arduino we are ready
Command numbers not in sync (Pi: 10; Arduino: 9)
One raw taken (0.683s); Told Arduino we are ready
Command numbers not in sync (Pi: 12; Arduino: 11)
One raw taken (0.89s); Told Arduino we are ready
Command numbers not in sync (Pi: 14; Arduino: 13)
One raw taken (0.704s); Told Arduino we are ready
Command numbers not in sync (Pi: 0; Arduino: 15)
One raw taken (1.11s); Told Arduino we are ready
Command numbers not in sync (Pi: 2; Arduino: 1)
One raw taken (0.87s); Told Arduino we are ready
Command numbers not in sync (Pi: 4; Arduino: 3)
One raw taken (0.736s); Told Arduino we are ready
Command numbers not in sync (Pi: 6; Arduino: 5)
One raw taken (0.752s); Told Arduino we are ready
Command numbers not in sync (Pi: 8; Arduino: 7)
One raw taken (0.951s); Told Arduino we are ready
Command numbers not in sync (Pi: 10; Arduino: 9)
One raw taken (0.784s); Told Arduino we are ready
Command numbers not in sync (Pi: 12; Arduino: 11)
One raw taken (1.34s); Told Arduino we are ready
Command numbers not in sync (Pi: 14; Arduino: 13)
One raw taken (0.701s); Told Arduino we are ready
Command numbers not in sync (Pi: 0; Arduino: 15)
One raw taken (0.725s); Told Arduino we are ready
Command numbers not in sync (Pi: 2; Arduino: 1)
One raw taken (0.903s); Told Arduino we are ready
Command numbers not in sync (Pi: 4; Arduino: 3)
One raw taken (3.34s); Told Arduino we are ready
Command numbers not in sync (Pi: 6; Arduino: 5)
One raw taken (0.655s); Told Arduino we are ready
Command numbers not in sync (Pi: 8; Arduino: 7)
One raw taken (0.923s); Told Arduino we are ready
Command numbers not in sync (Pi: 10; Arduino: 9)
One raw taken (0.714s); Told Arduino we are ready
Command numbers not in sync (Pi: 12; Arduino: 11)
One raw taken (1.2s); Told Arduino we are ready
Command numbers not in sync (Pi: 14; Arduino: 13)
One raw taken (0.704s); Told Arduino we are ready
Command numbers not in sync (Pi: 0; Arduino: 15)
One raw taken (0.739s); Told Arduino we are ready
Command numbers not in sync (Pi: 2; Arduino: 1)
One raw taken (0.757s); Told Arduino we are ready
Command numbers not in sync (Pi: 4; Arduino: 3)
One raw taken (0.751s); Told Arduino we are ready
Command numbers not in sync (Pi: 6; Arduino: 5)
One raw taken (1.16s); Told Arduino we are ready
Command numbers not in sync (Pi: 8; Arduino: 7)
One raw taken (0.737s); Told Arduino we are ready
Command numbers not in sync (Pi: 10; Arduino: 9)
One raw taken (0.737s); Told Arduino we are ready
Command numbers not in sync (Pi: 12; Arduino: 11)
One raw taken (0.734s); Told Arduino we are ready
Command numbers not in sync (Pi: 14; Arduino: 13)
One raw taken (0.736s); Told Arduino we are ready
Command numbers not in sync (Pi: 0; Arduino: 15)
One raw taken (0.718s); Told Arduino we are ready
Command numbers not in sync (Pi: 2; Arduino: 1)
One raw taken (0.723s); Told Arduino we are ready
Command numbers not in sync (Pi: 4; Arduino: 3)
One raw taken (0.734s); Told Arduino we are ready
Command numbers not in sync (Pi: 6; Arduino: 5)
One raw taken (0.735s); Told Arduino we are ready
Command numbers not in sync (Pi: 8; Arduino: 7)
One raw taken (0.733s); Told Arduino we are ready
Command numbers not in sync (Pi: 10; Arduino: 9)
One raw taken (0.747s); Told Arduino we are ready
Command numbers not in sync (Pi: 12; Arduino: 11)
One raw taken (0.742s); Told Arduino we are ready
Command numbers not in sync (Pi: 14; Arduino: 13)
One raw taken (0.711s); Told Arduino we are ready
Command numbers not in sync (Pi: 0; Arduino: 15)
One raw taken (0.698s); Told Arduino we are ready
Command numbers not in sync (Pi: 2; Arduino: 1)
One raw taken (0.732s); Told Arduino we are ready
Command numbers not in sync (Pi: 4; Arduino: 3)
One raw taken (0.712s); Told Arduino we are ready
Command numbers not in sync (Pi: 6; Arduino: 5)
One raw taken (0.721s); Told Arduino we are ready
Command numbers not in sync (Pi: 8; Arduino: 7)
One raw taken (0.723s); Told Arduino we are ready
Command numbers not in sync (Pi: 10; Arduino: 9)
One raw taken (0.724s); Told Arduino we are ready
Command numbers not in sync (Pi: 12; Arduino: 11)
One raw taken (0.737s); Told Arduino we are ready
Command numbers not in sync (Pi: 14; Arduino: 13)
One raw taken (0.776s); Told Arduino we are ready
Command numbers not in sync (Pi: 0; Arduino: 15)
One raw taken (1.17s); Told Arduino we are ready
Command numbers not in sync (Pi: 2; Arduino: 1)
One raw taken (0.687s); Told Arduino we are ready
Command numbers not in sync (Pi: 4; Arduino: 3)
One raw taken (0.69s); Told Arduino we are ready
Command numbers not in sync (Pi: 6; Arduino: 5)
One raw taken (0.724s); Told Arduino we are ready
Command numbers not in sync (Pi: 8; Arduino: 7)
One raw taken (0.74s); Told Arduino we are ready
Command numbers not in sync (Pi: 10; Arduino: 9)
One raw taken (0.715s); Told Arduino we are ready
Command numbers not in sync (Pi: 12; Arduino: 11)
One raw taken (5.29s); Told Arduino we are ready
Command numbers not in sync (Pi: 14; Arduino: 13)
One raw taken (0.722s); Told Arduino we are ready
Command numbers not in sync (Pi: 0; Arduino: 15)
One raw taken (0.713s); Told Arduino we are ready
Command numbers not in sync (Pi: 2; Arduino: 1)
One raw taken (0.733s); Told Arduino we are ready
Command numbers not in sync (Pi: 4; Arduino: 3)
One raw taken (0.68s); Told Arduino we are ready
Command numbers not in sync (Pi: 6; Arduino: 5)
One raw taken (0.709s); Told Arduino we are ready
Command numbers not in sync (Pi: 8; Arduino: 7)
One raw taken (0.989s); Told Arduino we are ready
Command numbers not in sync (Pi: 10; Arduino: 9)
One raw taken (0.732s); Told Arduino we are ready
Command numbers not in sync (Pi: 12; Arduino: 11)
One raw taken (0.695s); Told Arduino we are ready
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

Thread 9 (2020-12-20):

convert.py chokes on broken input files

fwachsmuth, 2020-12-20:
would be good if it would fail nicer and just skip such files (and move them to a quarantine dir)

```
/Volumes/Filme/_piscan/raw-intermediates/2020-12-20T16_31_39/00001071.jpg converted to /Volumes/Filme/_piscan/DNGs/2020-12-20T16_31_39/CONTENTS/IMAGE/000000/00001071.dng
/Volumes/Filme/_piscan/raw-intermediates/2020-12-20T16_31_39/00001072.jpg converted to /Volumes/Filme/_piscan/DNGs/2020-12-20T16_31_39/CONTENTS/IMAGE/000000/00001072.dng
/Volumes/Filme/_piscan/raw-intermediates/2020-12-20T16_31_39/00001073.jpg converted to /Volumes/Filme/_piscan/DNGs/2020-12-20T16_31_39/CONTENTS/IMAGE/000000/00001073.dng
/Volumes/Filme/_piscan/raw-intermediates/2020-12-20T16_31_39/00001074.jpg converted to /Volumes/Filme/_piscan/DNGs/2020-12-20T16_31_39/CONTENTS/IMAGE/000000/00001074.dng
Exception in thread Thread-1:
Traceback (most recent call last):
  File "/usr/local/Cellar/python@3.9/3.9.1/Frameworks/Python.framework/Versions/3.9/lib/python3.9/threading.py", line 954, in _bootstrap_inner
    self.run()
  File "/Users/peaceman/code/Arduino/Piscanuino/watchdog/src/watchdog/observers/api.py", line 199, in run
    self.dispatch_events(self.event_queue, self.timeout)
  File "/Users/peaceman/code/Arduino/Piscanuino/watchdog/src/watchdog/observers/api.py", line 372, in dispatch_events
    handler.dispatch(event)
  File "/Users/peaceman/code/Arduino/Piscanuino/watchdog/src/watchdog/events.py", line 261, in dispatch
    {
  File "/Users/peaceman/code/Arduino/Piscanuino/convert.py", line 116, in on_moved
    convert_new_raw(self, event.dest_path)
  File "/Users/peaceman/code/Arduino/Piscanuino/convert.py", line 104, in convert_new_raw
    convert_raw(jpg_path, compress, output_dir, keep_jpgs)
  File "/Users/peaceman/code/Arduino/Piscanuino/convert.py", line 153, in convert_raw
    dng_file.write(converter.convert(
  File "/usr/local/lib/python3.9/site-packages/pydng/core.py", line 258, in convert
    rawFrame = self.__process__(image, process)
  File "/usr/local/lib/python3.9/site-packages/pydng/core.py", line 223, in __process__
    rawImage = self.__extractRAW__(input_file)
  File "/usr/local/lib/python3.9/site-packages/pydng/core.py", line 187, in __extractRAW__
    assert data[:4] == 'BRCM'.encode("ascii")
AssertionError
^CTraceback (most recent call last):
  File "/Users/peaceman/code/Arduino/Piscanuino/convert.py", line 216, in <module>
    time.sleep(1)
KeyboardInterrupt
```

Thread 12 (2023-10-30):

Schematic: Replace LM2576 with MP24943DN

fwachsmuth, 2023-10-30:
The MP24943DN takes 55V (vs 45V) — should be safer. The MP is also cheaper.

fwachsmuth, 2023-10-30:
not a priority

Closed 2023-10-30.

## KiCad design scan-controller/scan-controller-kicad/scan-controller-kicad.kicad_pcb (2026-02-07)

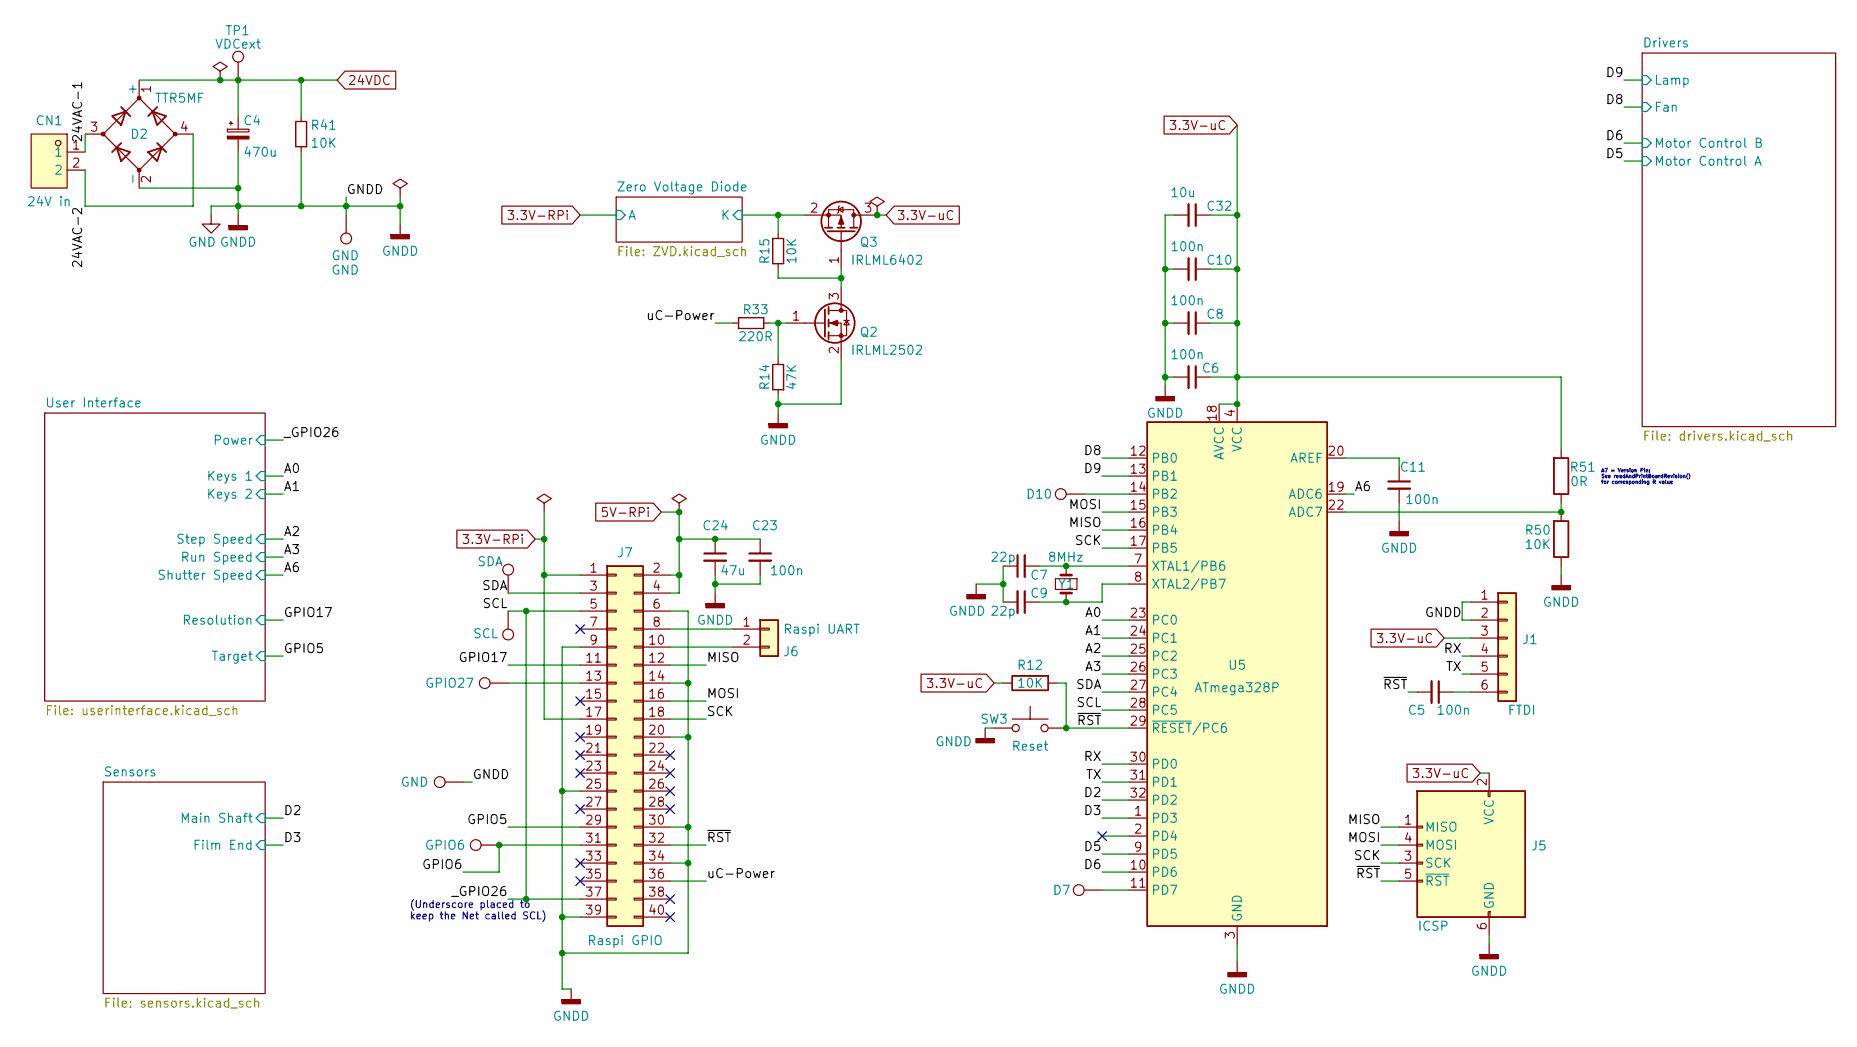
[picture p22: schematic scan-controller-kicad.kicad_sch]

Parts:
C4: 470u; CAP-SMD_BD12.5-L13.0-W13.0-RD; LCSC C487135
C5, C6, C8, C10, C11, C23: 100n; C_0805_2012Metric; LCSC C28233
C7, C9: 22p; C_0805_2012Metric; LCSC C1804
C24: 47u; C_1206_3216Metric; LCSC C96123
C32: 10u; C_1210_3225Metric; LCSC C5156756
CN1: 24V in; CONN-TH_2P-P5.08_KF142R-5.08-2P; LCSC C475144
D2: TTR5MF; DIO-BG-TH_TTF; LCSC C911077
J1: FTDI; PinHeader_1x06_P2.54mm_Vertical
J5: ICSP; PinHeader_2x03_P2.54mm_Vertical
J6: Raspi UART; PinHeader_1x02_P2.54mm_Vertical
J7: Raspi GPIO; PinSocket_2x20_P2.54mm_Vertical
Q2: IRLML2502; SOT-23; LCSC C347503
Q3: IRLML6402; SOT-23; LCSC C2886430
R12, R15, R50: 10K; R_0805_2012Metric; LCSC C17414
R14: 47K; R_0805_2012Metric; LCSC C17713
R33: 220R; R_0805_2012Metric; LCSC C17557
R41: 10K; R_1206_3216Metric; LCSC C17902
R51: 0R; R_0805_2012Metric; LCSC C17477
SW3: Reset; SW_Push_1P1T_XKB_TS-1187A; LCSC C318884
TP1: 24V; TestPoint_THTPad_1.5x1.5mm_Drill0.7mm_named
TP2, TP11: GND; TestPoint_THTPad_1.5x1.5mm_Drill0.7mm_named
TP4: D7; TestPoint_THTPad_1.5x1.5mm_Drill0.7mm_named
TP5, TP6: TestPoint; TestPoint_THTPad_1.5x1.5mm_Drill0.7mm_named
TP8: D10; TestPoint_THTPad_1.5x1.5mm_Drill0.7mm_named
TP12: GPIO27; TestPoint_THTPad_1.5x1.5mm_Drill0.7mm_named
TP13: GPIO6; TestPoint_THTPad_1.5x1.5mm_Drill0.7mm_named
U5: ATmega328P; TQFP-32_7x7mm_P0.8mm; LCSC C14877
Y1: 8MHz; Crystal_SMD_5032-2Pin_5.0x3.2mm; LCSC C115962

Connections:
3.3V-RPi: J7.1, J7.17; also elsewhere on the board
3.3V-uC: C6.1, C8.1, C10.1, C32.1, J1.3, J5.2 (VCC), Q3.3 (D), R12.1, R51.2, U5.4 (VCC), U5.6 (VCC), U5.18 (AVCC); also elsewhere on the board
5V-RPi: C23.1, C24.1, J7.2, J7.4; also elsewhere on the board
24VDC: C4.1, D2.1 (+), R41.2, TP1.1; also elsewhere on the board
/24VAC-1: CN1.1, D2.3
/24VAC-2: CN1.2, D2.4
/A0: U5.23 (PC0); also elsewhere on the board
/A1: U5.24 (PC1); also elsewhere on the board
/A2: U5.25 (PC2); also elsewhere on the board
/A3: U5.26 (PC3); also elsewhere on the board
/A6: U5.19 (ADC6); also elsewhere on the board
/D2: U5.32 (PD2); also elsewhere on the board
/D3: U5.1 (PD3); also elsewhere on the board
/D5: U5.9 (PD5); also elsewhere on the board
/D6: U5.10 (PD6); also elsewhere on the board
/D8: U5.12 (PB0); also elsewhere on the board
/D9: U5.13 (PB1); also elsewhere on the board
/GPIO5: J7.29; also elsewhere on the board
/GPIO6: J7.31, TP13.1
/GPIO17: J7.11; also elsewhere on the board
/MISO: J5.1 (MISO), J7.12, U5.16 (PB4)
/MOSI: J5.4 (MOSI), J7.16, U5.15 (PB3)
/RX: J1.4, U5.30 (PD0)
/SCK: J5.3 (SCK), J7.18, U5.17 (PB5)
/SCL: J7.5, J7.37, TP6.1, U5.28 (PC5); also elsewhere on the board
/SDA: J7.3, TP5.1, U5.27 (PC4)
/TX: J1.5, U5.31 (PD1)
/Zero Voltage Diode/K: Q3.2 (S), R15.1; also elsewhere on the board
/uC-Power: J7.36, R33.1
/~RST: C5.2, J5.5 (~RST), J7.32, R12.2, SW3.1, U5.29 (~RESET/PC6)
GND: C4.2, C6.2, C7.1, C8.2, C9.2, C10.2, C11.2, C23.2, C24.2, C32.2, D2.2 (-), J1.1, J1.2, J5.6 (GND), J7.6, J7.9, J7.14, J7.20, J7.25, J7.30, J7.34, J7.39, Q2.2 (S), R14.1, R41.1, R50.1, SW3.2, TP2.1, TP11.1, U5.3 (GND), U5.5 (GND), U5.21 (GND); also elsewhere on the board
unnamed: C5.1, J1.6
unnamed: J6.1, J7.8
unnamed: J6.2, J7.10
unnamed: J7.13, TP12.1
unnamed: Q2.3 (D), Q3.1 (G), R15.2
unnamed: Q2.1 (G), R14.2, R33.2
unnamed: R50.2, R51.1, U5.22 (ADC7)
unnamed: C11.1, U5.20 (AREF)
unnamed: TP8.1, U5.14 (PB2)
unnamed: TP4.1, U5.11 (PD7)
unnamed: C7.2, U5.7 (XTAL1/PB6), Y1.1
unnamed: C9.1, U5.8 (XTAL2/PB7), Y1.2

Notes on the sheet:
A7 = Version Pin: See readAndPrintBoardRevision() for corresponding R value
(Underscore placed to keep the Net called SCL)

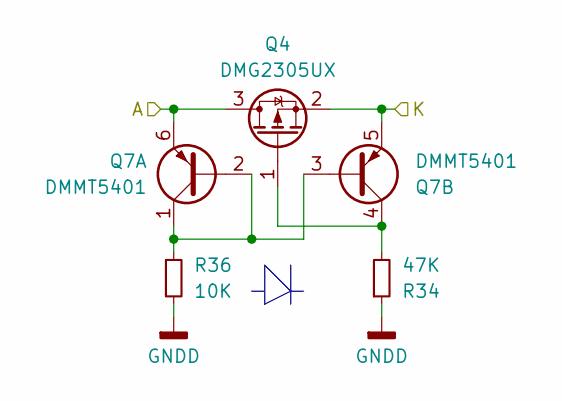
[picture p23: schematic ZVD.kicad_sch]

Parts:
Q4: DMG2305UX; SOT-23; LCSC C2940629
Q7: DMMT5401; SOT-23-6; LCSC C154733
R34: 47K; R_0805_2012Metric; LCSC C17713
R36: 10K; R_0805_2012Metric; LCSC C17414

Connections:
3.3V-RPi: Q4.3 (D), Q7.6 (E1); also elsewhere on the board
/Zero Voltage Diode/K: Q4.2 (S), Q7.5 (E2); also elsewhere on the board
GND: R34.1, R36.2; also elsewhere on the board
unnamed: Q4.1 (G), Q7.4 (C2), R34.2
unnamed: Q7.1 (C1), Q7.2 (B1), Q7.3 (B2), R36.1

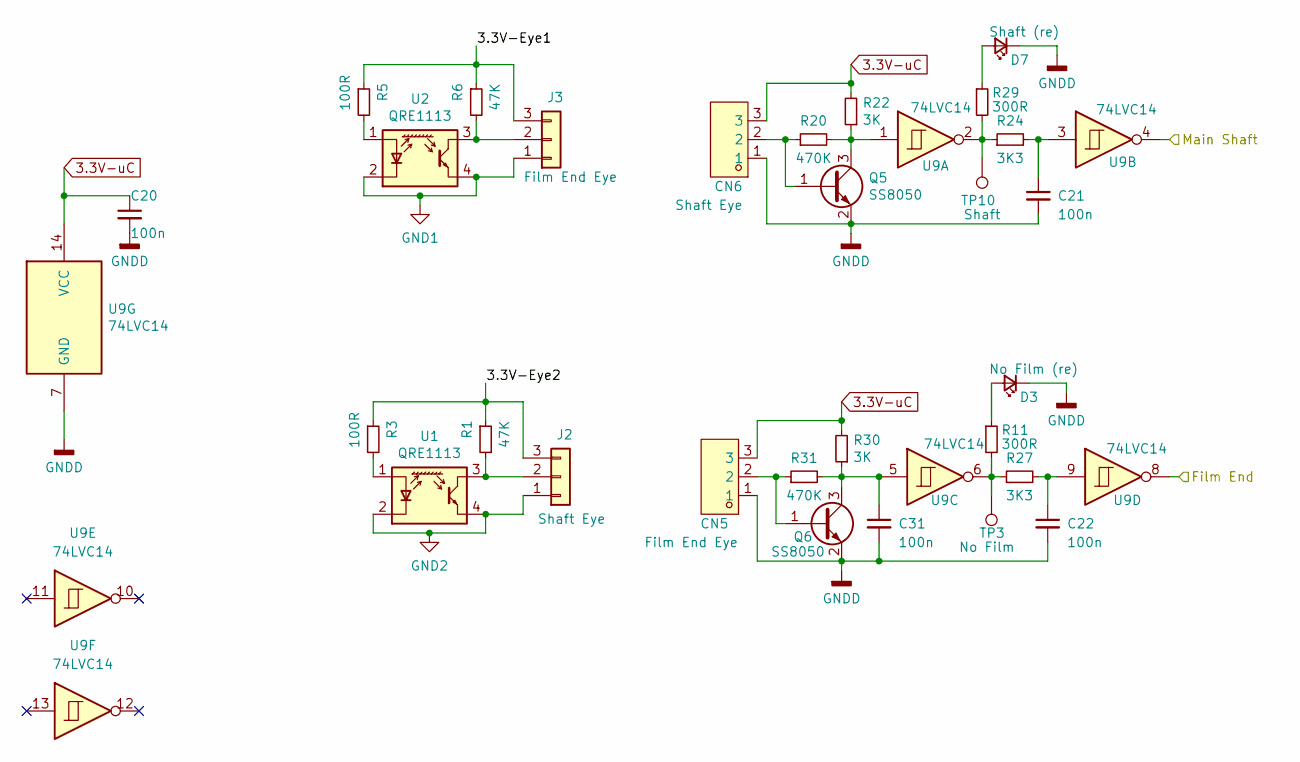
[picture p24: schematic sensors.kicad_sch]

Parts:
C20, C21, C22, C31: 100n; C_0805_2012Metric; LCSC C28233
CN5: Film End Eye; CONN-TH_3P-P2.54_DIBO_DB141R-2.54-3P; LCSC C2898755
CN6: Shaft Eye; CONN-TH_3P-P2.54_DIBO_DB141R-2.54-3P; LCSC C2898755
D3: No Film (re); LED_0805_2012Metric; LCSC C84256
D7: Shaft (re); LED_0805_2012Metric; LCSC C84256
J2: Shaft Eye; PinHeader_1x03_P2.54mm_Vertical
J3: Film End Eye; PinHeader_1x03_P2.54mm_Vertical
Q5, Q6: SS8050; SOT-23; LCSC C2150
R1, R6: 47K; R_0603_1608Metric; LCSC C25819
R3, R5: 100R; R_0603_1608Metric; LCSC C22775
R11, R29: 300R; R_0805_2012Metric; LCSC C17617
R20, R31: 470K; R_0805_2012Metric; LCSC C17709
R22, R30: 3K; R_0805_2012Metric; LCSC C17661
R24, R27: 3K3; R_0805_2012Metric; LCSC C26010
TP3: Film End; TestPoint_THTPad_1.5x1.5mm_Drill0.7mm_named
TP10: Main Shaft; TestPoint_THTPad_1.5x1.5mm_Drill0.7mm_named
U1, U2: QRE1113; OPTO-SMD_QRE1113GR; LCSC C232862
U9: 74LVC14; SOIC-14_3.9x8.7mm_P1.27mm

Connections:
3.3V-uC: C20.1, CN5.3, CN6.3, R22.2, R30.2, U9.14 (VCC); also elsewhere on the board
/D2: U9.4; also elsewhere on the board
/D3: U9.8; also elsewhere on the board
/Sensors/3.3V-Eye1: J3.3, R5.1, R6.1
/Sensors/3.3V-Eye2: J2.3, R1.1, R3.1
GND: C20.2, C21.2, C22.2, C31.2, CN5.1, CN6.1, D3.1 (K), D7.1 (K), Q5.2 (E), Q6.2 (E), U9.7 (GND); also elsewhere on the board
GND1: J3.1, U2.2 (K), U2.4
GND2: J2.1, U1.2 (K), U1.4
unnamed: C21.1, R24.2, U9.3
unnamed: C22.1, R27.2, U9.9
unnamed: D3.2 (A), R11.1
unnamed: D7.2 (A), R29.1
unnamed: J2.2, R1.2, U1.3
unnamed: J3.2, R6.2, U2.3
unnamed: CN6.2, Q5.1 (B), R20.1
unnamed: Q5.3 (C), R20.2, R22.1, U9.1
unnamed: CN5.2, Q6.1 (B), R31.1
unnamed: C31.1, Q6.3 (C), R30.1, R31.2, U9.5
unnamed: R11.2, R27.1, TP3.1, U9.6
unnamed: R24.1, R29.2, TP10.1, U9.2
unnamed: R3.2, U1.1 (A)
unnamed: R5.2, U2.1 (A)

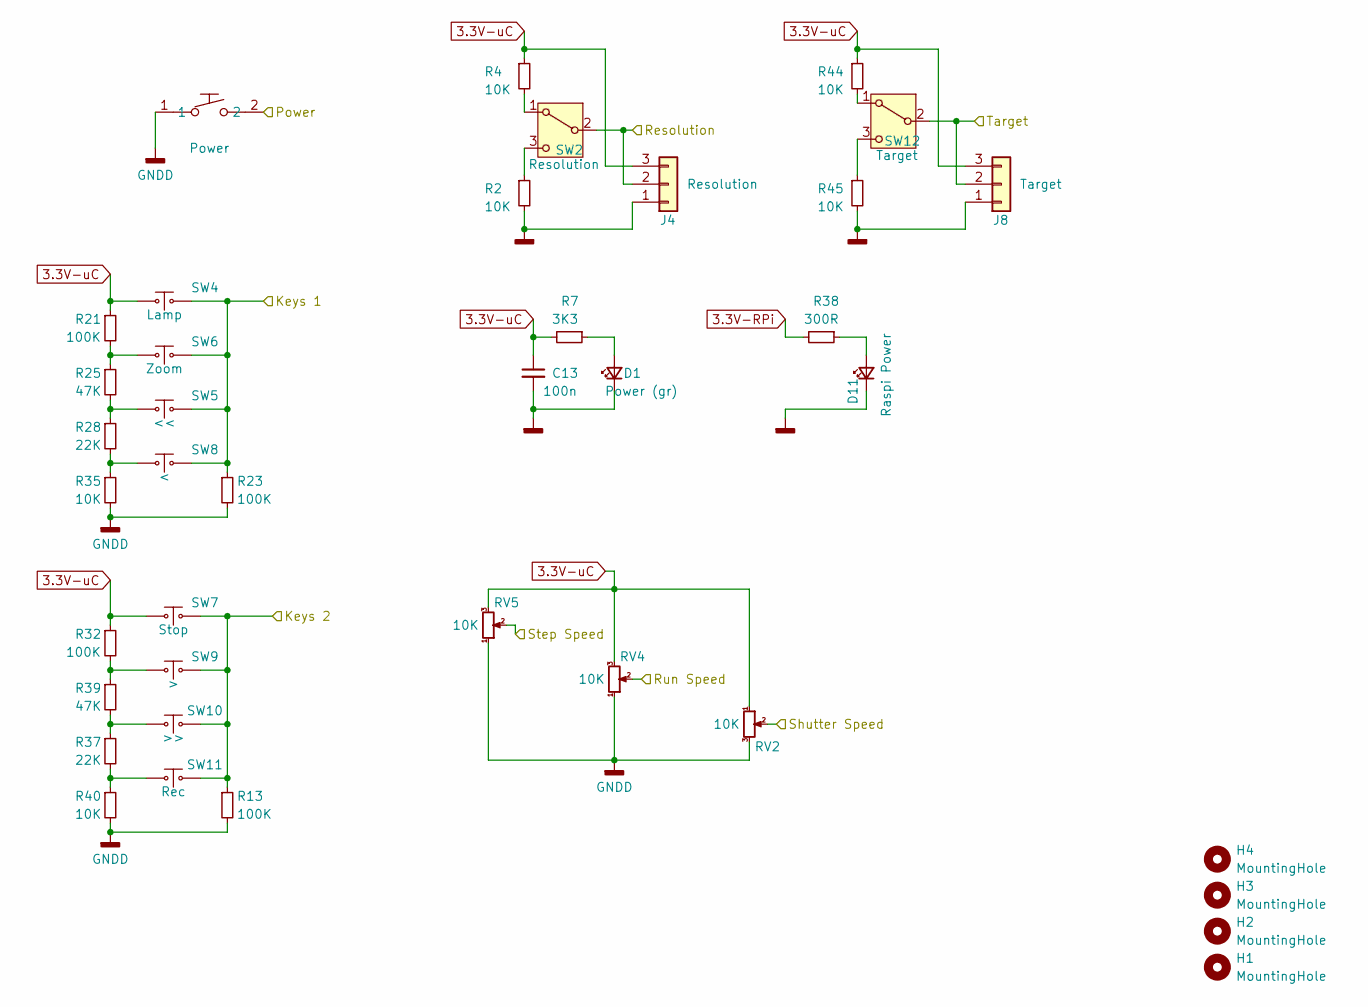
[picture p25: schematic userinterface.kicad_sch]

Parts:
C13: 100n; C_0805_2012Metric; LCSC C28233
D1: Power (gr); LED_0805_2012Metric; LCSC C2297
D11: Raspi Power; LED_0805_2012Metric; LCSC C84256
H1, H2, H3, H4: MountingHole; MountingHole_3.2mm_M3_Pad_Via
J4: Resolution; PinHeader_1x03_P2.54mm_Vertical
J8: Target; PinHeader_1x03_P2.54mm_Vertical
R2, R4, R35, R40, R44, R45: 10K; R_0805_2012Metric; LCSC C17414
R7: 3K3; R_0805_2012Metric; LCSC C26010
R13, R21, R23, R32: 100K; R_0805_2012Metric; LCSC C149504
R25, R39: 47K; R_0805_2012Metric; LCSC C17713
R28, R37: 22K; R_0805_2012Metric; LCSC C17560
R38: 300R; R_0805_2012Metric; LCSC C17617
RV2: 10K; RES-ADJ-TH_3P-L10.0-W10.0-P2.50-L; LCSC C118954
RV4, RV5: 10K; RES-TH_RK09K1110A0J_short; LCSC C209767
SW1: Power; KEY-TH_1825027-8; LCSC Part C231320
SW2: Resolution; SW-TH_5P-P4.70_SS-12D11-G040; LCSC C17179527
SW4: Lamp; KEY-TH_4P-L12.0-W12.0-P5.0-LS12.5-EH-small; LCSC Part C93156
SW5: <<; KEY-TH_4P-L12.0-W12.0-P5.0-LS12.5-EH-small; LCSC Part C93156
SW6: Zoom; KEY-TH_4P-L12.0-W12.0-P5.0-LS12.5-EH-small; LCSC Part C93156
SW7: Stop; KEY-TH_4P-L12.0-W12.0-P5.0-LS12.5-EH-small; LCSC Part C93156
SW8: <; KEY-TH_4P-L12.0-W12.0-P5.0-LS12.5-EH-small; LCSC Part C93156
SW9: >; KEY-TH_4P-L12.0-W12.0-P5.0-LS12.5-EH-small; LCSC Part C93156
SW10: >>; KEY-TH_4P-L12.0-W12.0-P5.0-LS12.5-EH-small; LCSC Part C93156
SW11: Rec; KEY-TH_4P-L12.0-W12.0-P5.0-LS12.5-EH-small; LCSC Part C93156
SW12: Target; SW-TH_5P-P4.70_SS-12D11-G040; LCSC C17179527

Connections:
3.3V-RPi: R38.2; also elsewhere on the board
3.3V-uC: C13.1, J4.3, J8.3, R4.1, R7.2, R21.1, R32.1, R44.1, RV2.1, RV4.3, RV5.3, SW4.3, SW4.4, SW7.3, SW7.4; also elsewhere on the board
/A0: R23.1, SW4.1, SW4.2, SW5.1, SW5.2, SW6.1, SW6.2, SW8.1, SW8.2; also elsewhere on the board
/A1: R13.1, SW7.1, SW7.2, SW9.1, SW9.2, SW10.1, SW10.2, SW11.1, SW11.2; also elsewhere on the board
/A2: RV5.2; also elsewhere on the board
/A3: RV4.2; also elsewhere on the board
/A6: RV2.2; also elsewhere on the board
/GPIO5: J8.2, SW12.2 (B); also elsewhere on the board
/GPIO17: J4.2, SW2.2 (B); also elsewhere on the board
/SCL: SW1.2; also elsewhere on the board
GND: C13.2, D1.1 (K), D11.1 (K), J4.1, J8.1, R2.2, R13.2, R23.2, R35.2, R40.2, R45.2, RV2.3, RV4.1, RV5.1, SW1.1; also elsewhere on the board
unnamed: D1.2 (A), R7.1
unnamed: D11.2 (A), R38.1
unnamed: R21.2, R25.1, SW6.3, SW6.4
unnamed: R25.2, R28.1, SW5.3, SW5.4
unnamed: R28.2, R35.1, SW8.3, SW8.4
unnamed: R32.2, R39.1, SW9.3, SW9.4
unnamed: R37.1, R39.2, SW10.3, SW10.4
unnamed: R37.2, R40.1, SW11.3, SW11.4
unnamed: R4.2, SW2.1 (A)
unnamed: R2.1, SW2.3 (C)
unnamed: R44.2, SW12.1 (A)
unnamed: R45.1, SW12.3 (C)

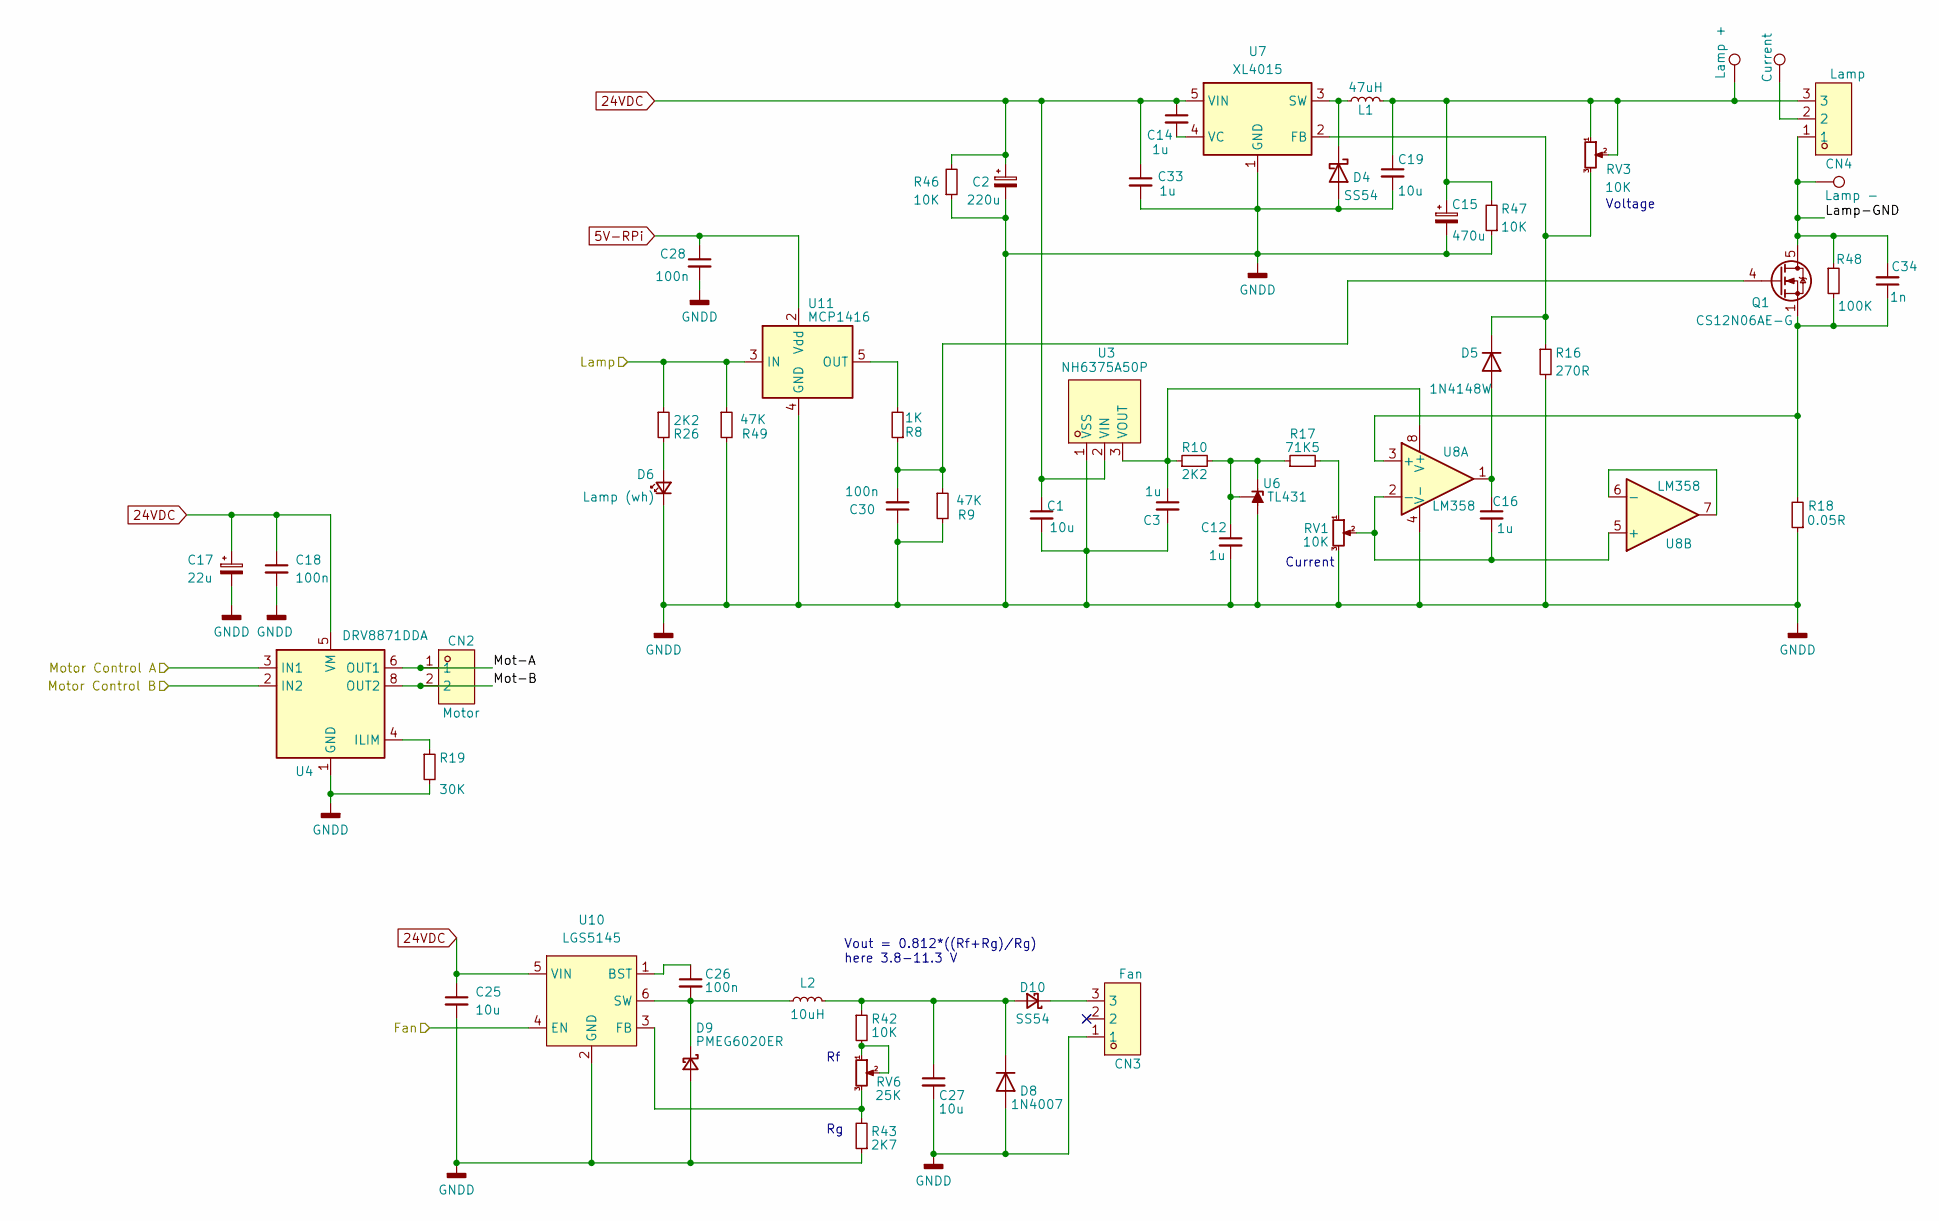
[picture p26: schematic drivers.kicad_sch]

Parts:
C1, C19, C25, C27: 10u; C_1210_3225Metric; LCSC C5156756
C2: 220u; CAP-SMD_BD12.5-L13.0-W13.0-FD; LCSC C249882
C3, C12, C14, C16, C33: 1u; C_0805_2012Metric; LCSC C22367837
C15: 470u; CAP-SMD_BD12.5-L13.0-W13.0-RD; LCSC C487135
C17: 22u; CP_Elec_6.3x7.7; LCSC C267472
C18, C26, C28, C30: 100n; C_0805_2012Metric; LCSC C28233
C34: 1n; C_0805_2012Metric; LCSC C15177
CN2: Motor; CONN-TH_2P-P5.08_KF142R-5.08-2P; LCSC C475144
CN3: Fan; CONN-TH_3P-P2.54_DIBO_DB141R-2.54-3P; LCSC C2898755
CN4: Lamp; CONN-TH_3P-P2.54_DIBO_DB141R-2.54-3P; LCSC C2898755
D4, D10: SS54; D_SMA; LCSC C22452
D5: 1N4148W; D_SOD-123; LCSC C81598
D6: Lamp (wh); LED_0805_2012Metric; LCSC C34499
D8: 1N4007; D_SOD-123F; LCSC C64898
D9: PMEG6020ER; D_SOD-123F; LCSC C52146084
L1: 47uH; IND-SMD_L13.8-W12.6_YSPI13XX; LCSC C497913
L2: 10uH; IND-SMD_L4.4-W4.2; LCSC C408339
Q1: CS12N06AE-G; SOIC-8_3.9x4.9mm_P1.27mm; LCSC C442412
R8: 1K; R_0805_2012Metric; LCSC C17513
R9, R49: 47K; R_0805_2012Metric; LCSC C17713
R10, R26: 2K2; R_0805_2012Metric; LCSC C17520
R16: 270R; R_0805_2012Metric; LCSC C137558
R17: 71K5; R_0805_2012Metric; LCSC C101850
R18: 0.05R; R_2512_6332Metric; LCSC C127698
R19: 30K; R_0805_2012Metric; LCSC C17621
R42: 10K; R_0805_2012Metric; LCSC C17414
R43: 2K7; R_0805_2012Metric; LCSC C17530
R46, R47: 10K; R_1206_3216Metric; LCSC C17902
R48: 100K; R_0805_2012Metric; LCSC C149504
RV1, RV3: 10K; RES-ADJ-TH_3P-L10.0-W10.0-P2.50-L; LCSC C118954
RV6: 25K; RES-ADJ-TH_3P-L10.0-W10.0-P2.50-L; LCSC C118932
TP14, TP15, TP16: TestPoint; TestPoint_THTPad_1.5x1.5mm_Drill0.7mm_named
U3: NH6375A50P; SOT-89-3_L4.5-W2.5-P1.50-LS4.2-BR; LCSC C7427778
U4: DRV8871DDA; Texas_HTSOP-8-1EP_3.9x4.9mm_P1.27mm_EP2.95x4.9mm_Mask2.4x3.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; LCSC C75864
U6: TL431; SOT-23; LCSC C181103
U7: XL4015; TO-263-5_TabPin3; LCSC C51661
U8: LM358; SOIC-8_3.9x4.9mm_P1.27mm; LCSC C7950
U10: LGS5145; SOT-23-6_L2.9-W1.7-P0.95-LS2.8-BL; LCSC Part C5123971
U11: MCP1416; SOT-23-5; LCSC C83775

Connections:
5V-RPi: C28.1, U11.2 (Vdd); also elsewhere on the board
24VDC: C1.1, C2.1, C14.1, C17.1, C18.1, C25.1, C33.1, R46.2, U3.2 (VIN), U4.5 (VM), U7.5 (VIN), U10.5 (VIN); also elsewhere on the board
/D5: U4.3 (IN1); also elsewhere on the board
/D6: U4.2 (IN2); also elsewhere on the board
/D8: U10.4 (EN); also elsewhere on the board
/D9: R26.1, R49.1, U11.3 (IN); also elsewhere on the board
/Drivers/Lamp-GND: C34.2, CN4.1, Q1.5 (D), Q1.6 (D), Q1.7 (D), Q1.8 (D), R48.1, TP14.1
/Drivers/Mot-A: CN2.1, U4.6 (OUT1)
/Drivers/Mot-B: CN2.2, U4.8 (OUT2)
GND: C1.2, C2.2, C3.2, C12.2, C15.2, C17.2, C18.2, C19.2, C25.2, C27.2, C28.2, C30.1, C33.2, CN3.1, D4.2 (A), D6.1 (K), D8.2 (A), D9.2 (A), R9.2, R16.2, R18.1, R19.2, R43.1, R46.1, R47.1, R49.2, RV1.3, U3.1 (VSS), U4.1 (GND), U4.7 (GND), U4.9 (GND), U6.3 (A), U7.1 (GND), U8.4 (V-), U10.2 (GND), U11.4 (GND); also elsewhere on the board
unnamed: C15.1, C19.1, CN4.3, L1.2, R47.2, RV3.1, RV3.2, TP15.1
unnamed: CN4.2, TP16.1
unnamed: D4.1 (K), L1.1, U7.3 (SW)
unnamed: C16.1, D5.2 (A), U8.1
unnamed: D5.1 (K), R16.1, RV3.3, U7.2 (FB)
unnamed: D6.2 (A), R26.2
unnamed: C26.2, D9.1 (K), L2.1, U10.6 (SW)
unnamed: C27.1, D8.1 (K), D10.2 (A), L2.2, R42.1
unnamed: CN3.3, D10.1 (K)
unnamed: C30.2, Q1.4 (G), R8.1, R9.1
unnamed: R17.2, RV1.1
unnamed: R42.2, RV6.1, RV6.2
unnamed: C3.1, R10.1, U3.3 (VOUT), U8.8 (V+)
unnamed: R19.1, U4.4 (ILIM)
unnamed: C12.1, R10.2, R17.1, U6.1 (K), U6.2 (REF)
unnamed: C14.2, U7.4 (VC)
unnamed: C34.1, Q1.1 (S), Q1.2 (S), Q1.3 (S), R18.2, R48.2, U8.3 (+)
unnamed: C16.2, RV1.2, U8.2 (-), U8.5 (+)
unnamed: U8.6 (-), U8.7
unnamed: C26.1, U10.1 (BST)
unnamed: R43.2, RV6.3, U10.3 (FB)
unnamed: R8.2, U11.5 (OUT)

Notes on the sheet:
Current
Vout = 0.812*((Rf+Rg)/Rg) here 3.8-11.3 V
Voltage

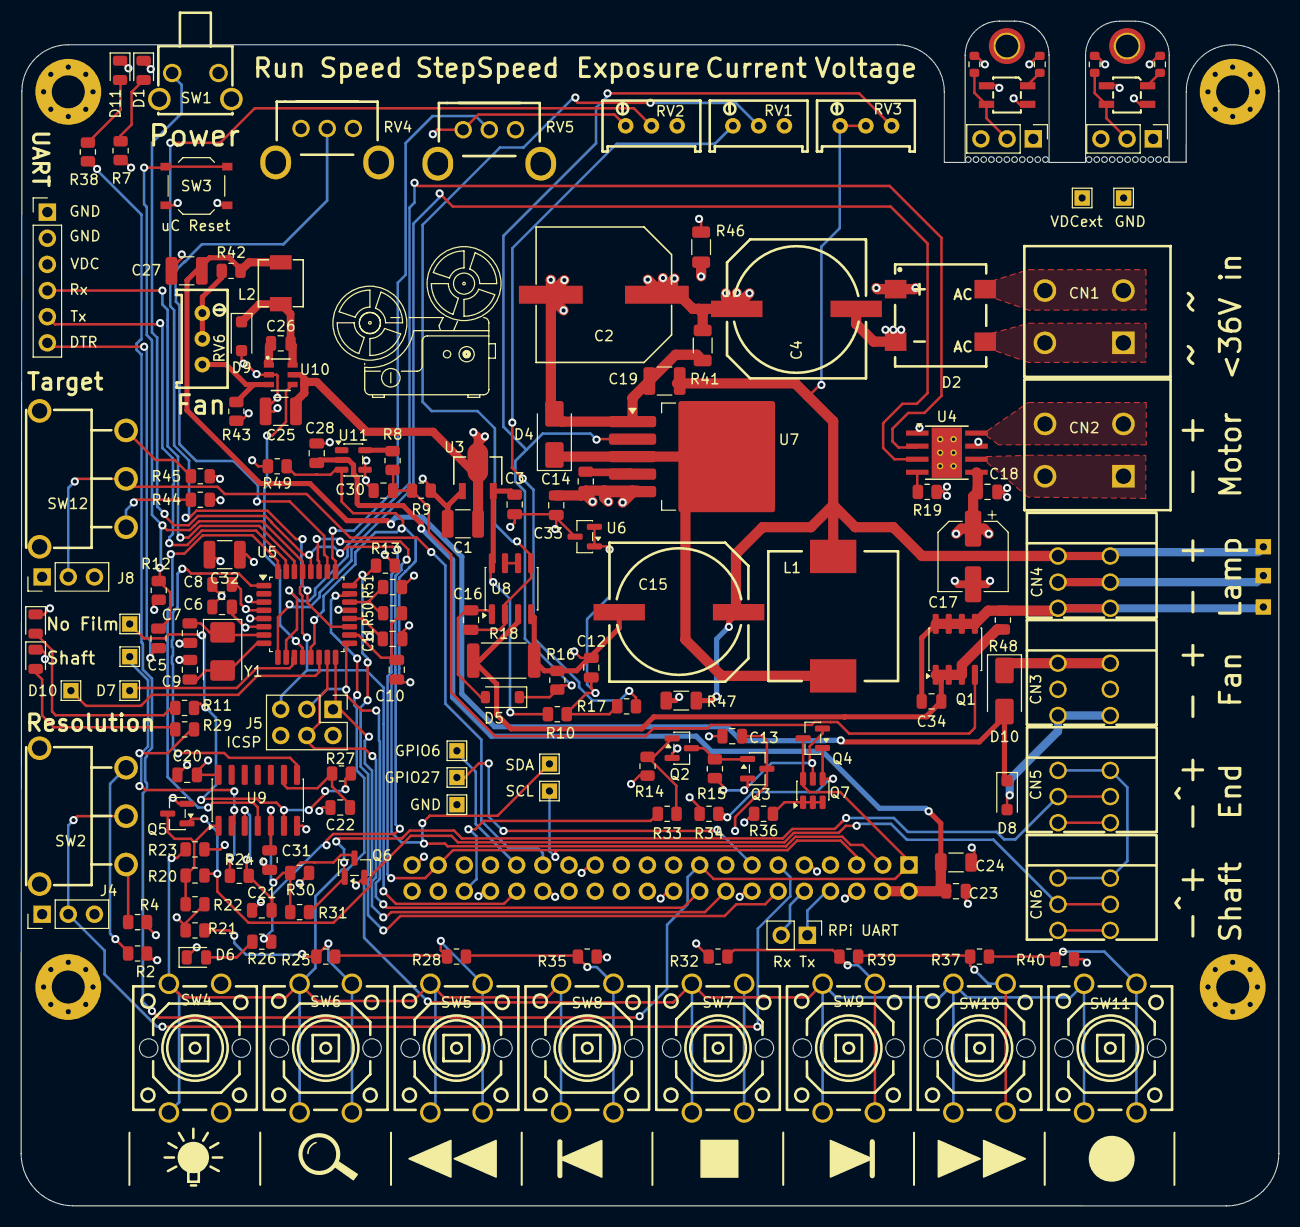
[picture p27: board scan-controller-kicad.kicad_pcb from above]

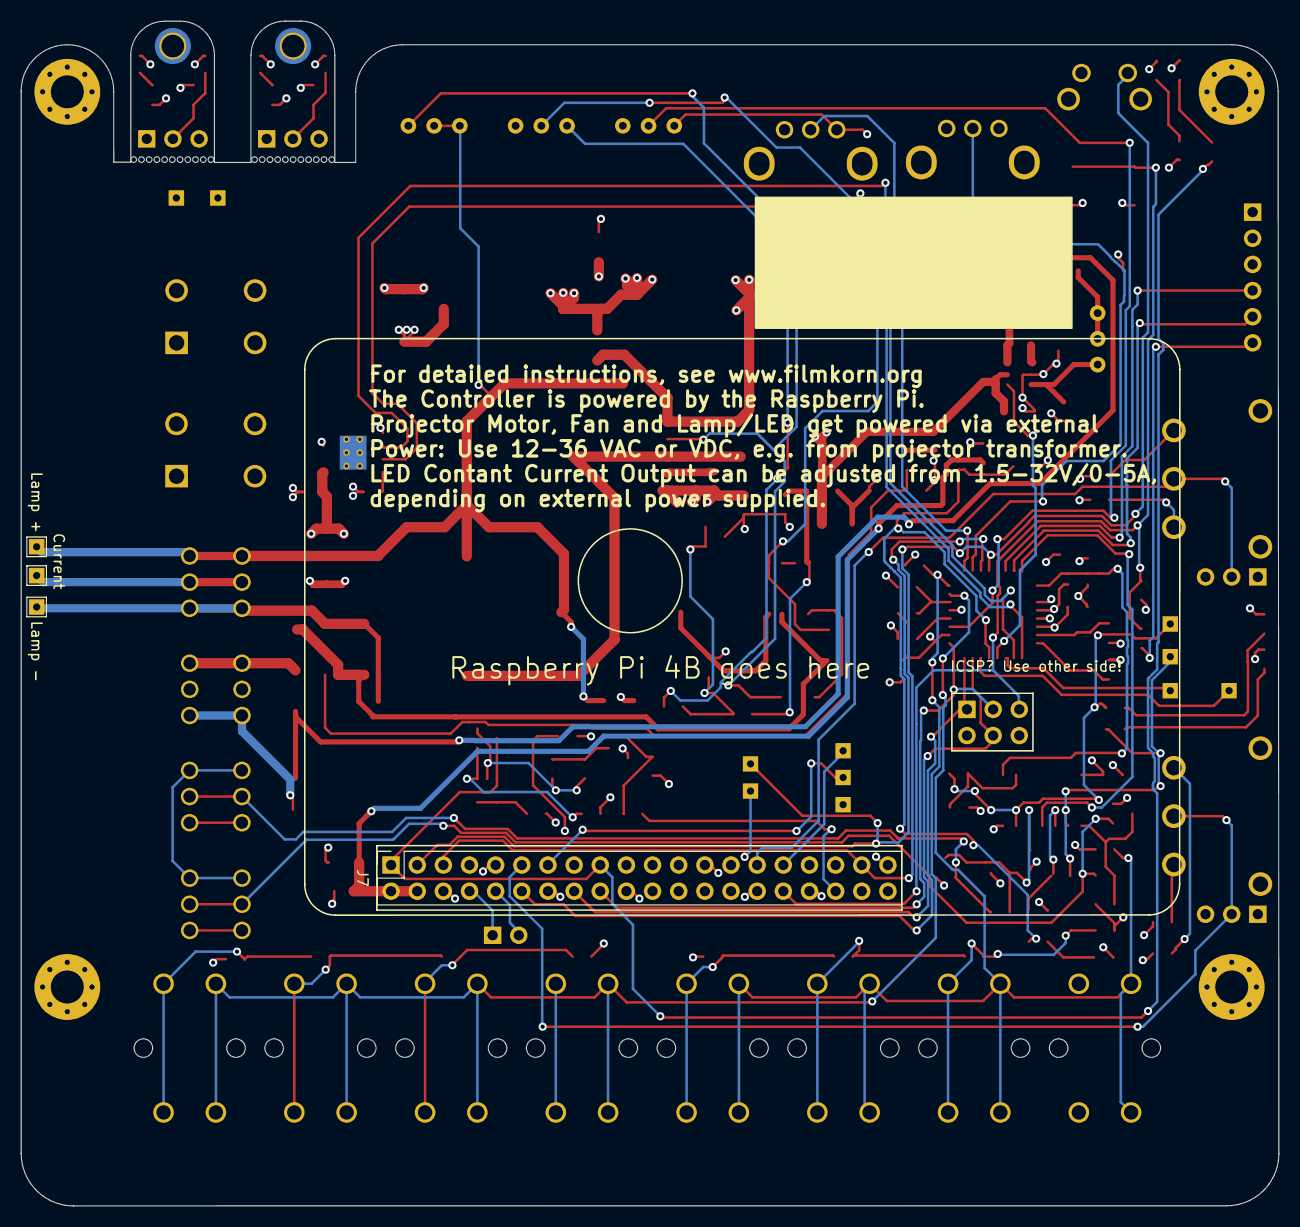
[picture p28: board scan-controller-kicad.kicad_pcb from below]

Board: 4 copper layers, 122.2 x 115.1 mm, 166 parts (4 on the bottom side), 100 nets.

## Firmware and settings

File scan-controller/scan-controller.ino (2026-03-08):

/*
 * Controller for the Noris based Film Scanner
 */

#include <avr/io.h>
#include <Wire.h>
#include <EEPROM.h>

#define EEPROM_CALIB_ADDR  0    // uint8_t motorMinDuty
#define EEPROM_MAGIC_ADDR  1    // magic byte to detect valid calibration data
#define EEPROM_CALIB_MAGIC 0xA5
#define EEPROM_BACKUP_MAGIC       0xC7
// Layout within the backup region (starting at EEPROM addr 5):
// [magic:1][len_lsb:1][len_msb:1][TLV...]
// Wipe = overwrite magic byte (offset 0 in region = absolute addr 5) with 0x00
#define EEPROM_BACKUP_BASE_ADDR   5     // backup region starts here

const byte SLAVE_ADDRESS = 42; // Our i2c address here
/*
i2c Setup:
The Raspi is the i2c Master (it can only be a master, and it isn't even running i2c, but SMBus.)
It polls the Arduino periodically for next thing to do, which is served by the i2cRequest() fuction, attached to the 
i2c ISR via `Wire.onRequest(i2cRequest);`in setup().

The response the Arduino sends is usually just one byte right now.
*/

// Define the Control Buttons
enum ControlButton {
  NONE,   // No Button pressed
  ZOOM,   // Toggle
  LIGHT,  // Toggle
  RUNREV, // Radio
  REV1,   // Push
  STOP,   // Radio
  FWD1,   // Push
  RUNFWD, // Radio
  SCAN    // Radio
};

// Define the motor states
enum MotorState {
  REV = -1,
  STOPPED,
  FWD
};

// Define the Hardware wiring
#define EYE_PIN         2 // ISR
#define FILM_END_PIN    3
#define MOTOR_B_PIN     5 // PWM
#define MOTOR_A_PIN     6 // PWM
#define FAN_PIN         8
#define LAMP_PIN        9
#define BUTTONS_A_PIN   A0
#define BUTTONS_B_PIN   A1
#define SINGLE_STEP_POT A2
#define CONT_RUN_POT    A3
#define EXPOSURE_POT    A6
#define REV_PIN         A7   // Board revision: voltage divider 10k to GND, R51 (VCC to A7) per revision

enum Command
{
  CMD_NONE,

  // Arduino to Raspi
  CMD_PING,
  CMD_Z1_1,  // Zoom Level 1:1
  CMD_Z3_1,  // Zoom Level 3:1
  CMD_Z10_1, // Zoom Level 6:1
  CMD_SHOOT_RAW,
  CMD_LAMP_OFF, // needs to stay at an even number
  CMD_LAMP_ON,
  CMD_START_SCAN,
  CMD_STOP_SCAN,
  CMD_SET_EXP, // set new exposure time per trimpot position
  CMD_SHOW_INSERT_FILM,
  CMD_SHOW_READY_TO_SCAN,
  CMD_SET_INITVALUES, // get load state and exposure pot value (both only get send when they change)
  CMD_UPDATE_ENTER,
  CMD_UPDATE_PREV,
  CMD_UPDATE_NEXT,
  CMD_UPDATE_CONFIRM,
  CMD_UPDATE_CANCEL,
  CMD_PAIRING_ENTER,
  CMD_PAIRING_EXIT,
  CMD_PAIRING_CANCEL,
  CMD_LOGS_ENTER,
  CMD_LOGS_EXIT,
  CMD_UNPAIR_ENTER,
  CMD_UNPAIR_PREV,
  CMD_UNPAIR_NEXT,
  CMD_UNPAIR_CONFIRM,
  CMD_UNPAIR_CANCEL,
  CMD_AWB_ENTER = 30,
  CMD_AWB_PREV = 31,
  CMD_AWB_NEXT = 32,
  CMD_AWB_CONFIRM = 33,
  CMD_AWB_CANCEL = 34,
  CMD_TARGET_ENTER = 35,
  CMD_TARGET_PREV = 36,
  CMD_TARGET_NEXT = 37,
  CMD_TARGET_CONFIRM = 38,
  CMD_TARGET_CANCEL = 39,
  CMD_MENU_ENTER = 40,
  CMD_MENU_EXIT = 41,
  CMD_MENU_PREV = 42,
  CMD_MENU_NEXT = 43,
  CMD_MENU_SELECT = 44,
  CMD_WIFI_ENTER = 45,
  CMD_WIFI_PREV = 46,
  CMD_WIFI_NEXT = 47,
  CMD_WIFI_CONFIRM = 48,
  CMD_WIFI_CANCEL = 49,
  CMD_LATENCY_ENTER = 50,
  CMD_LATENCY_PREV = 51,
  CMD_LATENCY_NEXT = 52,
  CMD_LATENCY_CONFIRM = 53,
  CMD_LATENCY_CANCEL = 54,

  // EEPROM dotfile backup (bidirectional)
  CMD_EEPROM_WRITE_CHUNK = 55,   // Pi → Arduino: [offset_hi, offset_lo, data...]
  CMD_EEPROM_READ_REQUEST = 56,  // Pi → Arduino: [offset_hi, offset_lo, length]
  CMD_EEPROM_WIPE = 57,          // Pi → Arduino: wipe backup magic byte
  CMD_EEPROM_DATA = 58,          // Arduino → Pi: buffered read data (follows CMD_EEPROM_READ_REQUEST)

  // Motor calibration (bidirectional)
  CMD_CALIB_MOTOR_START = 61,    // Arduino → Pi: calibration starting (Pi shows status screen, exits menu)
  CMD_SET_MOTOR_CALIB = 59,      // Pi → Arduino: [motorMinDuty] — apply stored calibration on startup
  CMD_MOTOR_CALIB_RESULT = 60,   // Arduino → Pi: [motorMinDuty] — calibration result to save as dotfile

  // Raspi to Arduino
  CMD_READY = 128,
  CMD_TELL_INITVALUES = 129, // send film load state and exposure pot value (both only get send when they change)
  CMD_TELL_LOADSTATE = 130,
  CMD_AWB_EXIT = 131,
  CMD_TARGET_EXIT = 132,
  CMD_TARGET_REENTER = 133,  // Re-enter target mode (used when returning from validation error)
  CMD_WIFI_EXIT = 134,
  CMD_SCAN_REJECTED = 135,   // Pi rejected START_SCAN (e.g. no drive / not paired)
  CMD_LATENCY_EXIT = 136,    // Pi tells Arduino to exit latency submenu

  CMD_LOCALE_ENTER   = 62,   // Arduino → Pi: enter language selection submenu
  CMD_LOCALE_PREV    = 63,   // Arduino → Pi
  CMD_LOCALE_NEXT    = 64,   // Arduino → Pi
  CMD_LOCALE_CONFIRM = 65,   // Arduino → Pi
  CMD_LOCALE_CANCEL  = 66,   // Arduino → Pi
  CMD_LOCALE_EXIT    = 137,  // Pi → Arduino: exit locale submenu

  // Film-end sensor mode (bidirectional)
  CMD_FILMEND_ENTER    = 67,   // Arduino → Pi: enter film-end sensor submenu
  CMD_FILMEND_PREV     = 68,   // Arduino → Pi
  CMD_FILMEND_NEXT     = 69,   // Arduino → Pi
  CMD_FILMEND_CONFIRM  = 70,   // Arduino → Pi
  CMD_FILMEND_CANCEL   = 71,   // Arduino → Pi
  CMD_SET_FILMEND_MODE = 72,   // Pi → Arduino: [mode] — apply stored film-end sensor mode
  CMD_FILMEND_EXIT     = 138,  // Pi → Arduino: exit film-end sensor submenu

  // Board revision (bidirectional)
  CMD_BOARD_REV        = 73,   // Arduino → Pi: [letter] — board revision letter (ASCII)
  CMD_TELL_BOARD_REV   = 139   // Pi → Arduino: request board revision
};

enum ZoomMode {
  Z1_1, //  1:1
  Z3_1, //  3:1
  Z10_1 // 10:1
};

enum FilmEndMode {
  FILMEND_NORMAL = 0,    // HIGH = film present, LOW = no film (default)
  FILMEND_INVERTED = 1,  // LOW = film present, HIGH = no film
  FILMEND_NONE = 2       // skip all checks, behave as if film always present
};

enum MenuState {
  MENU_IDLE,      // Normal operation
  MENU_MAIN,      // Main settings menu
  MENU_UPDATE,    // Firmware update submenu
  MENU_PAIRING,   // Pairing submenu
  MENU_AWB,       // White balance submenu
  MENU_LATENCY,   // Capture latency submenu
  MENU_TARGET,    // Scan target submenu
  MENU_WIFI,      // WiFi setup submenu
  MENU_LOGS,      // Debug log submenu
  MENU_UNPAIR,    // Factory reset submenu
  MENU_LOCALE,    // Language selection submenu
  MENU_FILMEND    // Film-end sensor submenu
};

enum MenuItem {
  MENU_ITEM_LANGUAGE = 0,
  MENU_ITEM_CALIB_MOTOR = 1,
  MENU_ITEM_CAPTURE_LATENCY = 2,
  MENU_ITEM_FILMEND = 3,
  MENU_ITEM_AWB = 4,
  MENU_ITEM_WIFI = 5,
  MENU_ITEM_PAIRING = 6,
  MENU_ITEM_TARGET = 7,
  MENU_ITEM_UPDATE = 8,
  MENU_ITEM_LOGS = 9,
  MENU_ITEM_UNPAIR = 10,
  MENU_ITEM_COUNT = 11
};


// Define some global variables
uint8_t motorMinDuty = 100;     // lower bound for pot mapping; updated by calibration
uint8_t fps18MotorPower = 0;
uint8_t singleStepMotorPower = 0;
int16_t exposurePot = 0;
int16_t lastSentExposurePot = -100;  // last value sent to Pi (init far away to trigger first send)
uint8_t filmLoadState;

bool lastFilmEndState;
bool filmEndState;
bool filmEndLowPending = false;
uint32_t filmEndLowSince = 0;
uint32_t fwdFilmInsertedSince = 0;  // when film first seen inserted in RUNFWD (0 = not yet; film-end stop only after 30s)


int dummyread; // for throw-away ADC reads (avoids multiplex-carryover of S&H cap charges)

bool lampMode = false;
bool lampModeBeforeScan = false;  // saved on SCAN entry, restored on SCAN_REJECTED
bool isScanning = false;
uint8_t scanExtraFrames = 0;  // frames to continue after film end detected
uint8_t filmEjectAdvances = 0;  // advances to eject film after scanning done
volatile bool singleStepInProgress = false;  // true while single-step motor advance is running
uint8_t scanFilmEndCount = 0;  // consecutive film-end reads needed to trigger end-of-roll
bool updateMode = false;
bool pairingMode = false;
bool logsMode = false;
bool awbMode = false;
bool latencyMode = false;
bool targetMode = false;
bool wifiMode = false;
bool localeMode = false;
bool filmEndMenuMode = false;
uint8_t filmEndSensorMode = FILMEND_NORMAL;
volatile bool targetReenterPending = false;
uint32_t pairingModeEnteredAt = 0;
bool pairingCancelPending = false;
uint32_t pairingCancelSentAt = 0;
uint32_t bootIgnoreUntil = 0;

// Menu system
MenuState menuState = MENU_IDLE;
uint8_t menuSelected = 0;  // Current selection in main menu
bool stopButtonPressed = false;
uint32_t stopButtonPressedAt = 0;
const uint32_t STOP_LONG_PRESS_MS = 2000;  // 2 seconds

volatile bool piIsReady = false;

// EEPROM backup: read buffer filled in loop() after CMD_EEPROM_READ_REQUEST, served by i2cRequest()
uint8_t eepromReadBuf[32];
uint8_t eepromReadLen = 0;
volatile bool eepromDataAvailable = false;     // set by loop() when eepromReadBuf is filled
volatile bool eepromServeNextRequest = false;  // set by i2cReceive when Pi sends CMD_EEPROM_DATA reg byte
// Deferred read request: set by ISR, consumed by loop() to avoid slow EEPROM reads inside ISR
volatile bool eepromReadPending = false;
volatile uint16_t eepromReadPendingOffset = 0;
volatile uint8_t eepromReadPendingLen = 0;
// Deferred write request: set by ISR, consumed by loop() to avoid slow EEPROM writes inside ISR
volatile bool eepromWritePending = false;
uint8_t eepromWriteBuf[32];
uint8_t eepromWriteLen = 0;
volatile uint16_t eepromWriteOffset = 0;

char boardRevision = '?';  // Set once in readAndPrintBoardRevision(), served via CMD_BOARD_REV

/*
 * Board revision is encoded on A7 via voltage divider: 10 kOhm to GND, R51 (VCC to A7) per revision.
 * 3.3 V reference. If A7 is floating (no R51), readings are unstable → report Rev. D.
 * E24 values for R51 per revision (Rev E = first released with this identifier):
 * Revisions:
 * E: 0 R (short)
 * F: 330 R
 * G: 1.1 k
 * H: 2.0 k
 * I: 3.0 k
 * J: 4.3 k
 * K: 5.6 k
 * L: 7.5 k
 * M: 10 k
 * N: 13 k 
 * O: 18 k 
 * P: 24 k, Q: 33 k, R: 56 k, Rev S: not populated (open).
 */
void readAndPrintBoardRevision() {
  const int numSamples = 8;
  const int maxSpread = 120;   // if (max - min) > this, consider A7 floating
  dummyread = analogRead(EXPOSURE_POT);
  int v0 = analogRead(REV_PIN);
  int sum = v0;
  int vmin = v0, vmax = v0;
  for (int i = 1; i < numSamples; i++) {
    dummyread = analogRead(REV_PIN);
    int v = analogRead(REV_PIN);
    sum += v;
    if (v < vmin) vmin = v;
    if (v > vmax) vmax = v;
  }
  int mean = sum / numSamples;
  if (vmax - vmin > maxSpread) {
    boardRevision = 'D';
    Serial.println(F("Rev. D"));
    return;
  }
  // 15 bands: E (highest ADC) .. S (lowest). Thresholds are lower bounds for each rev.
  static const uint16_t revThresholds[] = { 970, 905, 840, 775, 710, 645, 580, 515, 450, 385, 320, 255, 190, 125, 60 };
  const char revLetters[] = { 'E', 'F', 'G', 'H', 'I', 'J', 'K', 'L', 'M', 'N', 'O', 'P', 'Q', 'R', 'S' };
  int rev = 0;
  while (rev < 14 && mean < (int)revThresholds[rev + 1])
    rev++;
  boardRevision = revLetters[rev];
  Serial.print(F("Rev. "));
  Serial.println(revLetters[rev]);
}

ControlButton currentButton = NONE;
ControlButton prevButton = NONE;
uint8_t currentMotor = 0;
MotorState motorState = STOPPED;
volatile Command nextPiCmd = CMD_NONE;

ZoomMode zoomMode = Z1_1;

// Timer 0 prescaler is set to 1 in setup() to raise the PWM frequency on motor
// pins 5 & 6 from ~980 Hz (audible) to ~62.5 kHz (inaudible). As a side effect,
// millis() and delay() run 64x faster; use these wrappers everywhere instead.
#define TIMER0_PRESCALER_SCALE 64UL

unsigned long scaledMillis() {
  return millis() / TIMER0_PRESCALER_SCALE;
}

void scaledDelay(unsigned long ms) {
  delay(ms * TIMER0_PRESCALER_SCALE);
}

void setup() {  
  // Capture reset cause before any init clears it; then clear MCUSR for next reset.
  uint8_t mcusr = MCUSR;
  MCUSR = 0;

  // Immediately disable lamp to prevent brief flash during boot
  pinMode(LAMP_PIN, OUTPUT);
  digitalWrite(LAMP_PIN, LOW);

  Serial.begin(115200);

  // motorMinDuty default (100) is used until Pi sends CMD_SET_MOTOR_CALIB at startup
  // (EEPROM_CALIB_ADDR / EEPROM_MAGIC_ADDR bytes 0-1 are kept unused for layout compatibility)

  pinMode(BUTTONS_A_PIN, INPUT);
  pinMode(BUTTONS_B_PIN, INPUT);
  pinMode(SINGLE_STEP_POT, INPUT);
  pinMode(CONT_RUN_POT, INPUT);
  pinMode(EXPOSURE_POT, INPUT);
  pinMode(FAN_PIN, OUTPUT);
  pinMode(MOTOR_A_PIN, OUTPUT);
  pinMode(MOTOR_B_PIN, OUTPUT);
  pinMode(EYE_PIN, INPUT);
  pinMode(FILM_END_PIN, INPUT);
  pinMode(REV_PIN, INPUT);

  // Initialize film end state to current value to prevent spurious state change detection
  filmEndState = readFilmEndPin();
  lastFilmEndState = filmEndState;

  bootIgnoreUntil = scaledMillis() + 800;

  // Raise Timer 0 PWM to ~62.5 kHz (prescaler 1 instead of default 64).
  // See scaledMillis() / scaledDelay() above for the required compensation.
  TCCR0B = (TCCR0B & 0xF8) | 0x01;

  // Brake the motor (both HIGH = H-Bridge short-circuit brake, safer than freewheel on reset)
  digitalWrite(MOTOR_A_PIN, HIGH);
  digitalWrite(MOTOR_B_PIN, HIGH);
  digitalWrite(FAN_PIN, LOW);
  digitalWrite(LAMP_PIN, LOW);

  Wire.begin(SLAVE_ADDRESS);
  Wire.onReceive(i2cReceive);
  Wire.onRequest(i2cRequest);

  readAndPrintBoardRevision();
}

void loop() {
  if (!updateMode && scaledMillis() < bootIgnoreUntil) {
    currentButton = pollButtons();
    prevButton = currentButton;
    return;
  }

  // Handle deferred EEPROM read request from i2cReceive ISR.
  // EEPROM.read() takes ~3.4 ms/byte so must not run inside the ISR.
  if (eepromReadPending) {
    eepromReadPending = false;
    uint16_t offset = eepromReadPendingOffset;
    uint8_t length = eepromReadPendingLen;
    for (uint8_t i = 0; i < length; i++) {
      eepromReadBuf[i] = EEPROM.read(EEPROM_BACKUP_BASE_ADDR + offset + i);
    }
    eepromReadLen = length;
    eepromDataAvailable = true;
  }

  // Handle deferred EEPROM write request from i2cReceive ISR.
  // EEPROM.update() takes ~3.4 ms/byte so must not run inside the ISR.
  if (eepromWritePending) {
    eepromWritePending = false;
    uint16_t offset = eepromWriteOffset;
    uint8_t length = eepromWriteLen;
    for (uint8_t i = 0; i < length; i++) {
      EEPROM.update(EEPROM_BACKUP_BASE_ADDR + offset + i, eepromWriteBuf[i]);
    }
    if (length == 1 && offset == 0 && eepromWriteBuf[0] == 0x00) {
      Serial.println(F("EEPROM backup: wiped"));
    }
  }

  // Handle deferred target re-enter from i2cReceive ISR
  if (targetReenterPending) {
    targetReenterPending = false;
    // Python is telling us to enter target mode (e.g., due to network failure)
    // This can be called from MENU_IDLE, so we need to enter menu mode first
    if (menuState == MENU_IDLE) {
      menuState = MENU_MAIN;
      Serial.println(F("Target: entering menu mode first"));
    }
    targetMode = true;
    menuState = MENU_TARGET;
    nextPiCmd = CMD_NONE;
    // Poll buttons immediately to sync state - this prevents any button that was
    // pressed before entering menu mode from triggering actions
    currentButton = pollButtons();
    prevButton = currentButton;
    Serial.print(F("Target menu: re-enter (from Pi), menuState="));
    Serial.print(menuState);
    Serial.print(F(", targetMode="));
    Serial.println(targetMode);
  }

  // Handle menu system
  if (menuState != MENU_IDLE) {
    handleMenuSystem();
    return;
  }

  // Check for long-press STOP button to enter menu (only when idle/ready)
  // We need to check raw ADC value directly, not pollButtons(), because pollButtons()
  // only detects edge transitions and won't continuously return STOP while held
  // Only check for long-press if we're truly idle (not scanning, motor stopped, no single step)
  if (!isScanning && motorState == STOPPED && !singleStepInProgress) {
    dummyread = analogRead(BUTTONS_B_PIN);
    int buttonBankB = analogRead(BUTTONS_B_PIN);
    bool stopButtonCurrentlyPressed = (buttonBankB > 990);  // STOP button threshold
    
    if (stopButtonCurrentlyPressed) {
      if (!stopButtonPressed) {
        // Button just pressed - start timing
        stopButtonPressed = true;
        stopButtonPressedAt = scaledMillis();
        Serial.println(F("Menu: STOP button pressed, timing..."));
      } else {
        // Button still held - check if long enough
        uint32_t pressDuration = scaledMillis() - stopButtonPressedAt;
        if (pressDuration >= STOP_LONG_PRESS_MS) {
          // Long press detected - enter menu immediately
          menuState = MENU_MAIN;
          menuSelected = 0;
          stopButtonPressed = false;
          prevButton = NONE;  // Reset prevButton so menu navigation works
          currentButton = NONE;  // Reset currentButton
          nextPiCmd = CMD_MENU_ENTER;
          Serial.println(F("Menu: enter (long press STOP)"));
          return;
        }
      }
    } else {
      // Button not pressed or released
      if (stopButtonPressed) {
        // Button was pressed but released before long-press threshold
        uint32_t pressDuration = scaledMillis() - stopButtonPressedAt;
        Serial.print(F("Menu: STOP released after "));
        Serial.print(pressDuration);
        Serial.println(F(" ms (too short)"));
        // Reset button state so pollButtons() can detect the release and handle it normally
        stopButtonPressed = false;
        // Reset prevButton so the button release can be detected by normal handler
        prevButton = NONE;
      } else {
        stopButtonPressed = false;
      }
    }
  } else {
    // Not idle - reset long-press state
    stopButtonPressed = false;
  }

  currentButton = pollButtons();
  if (isScanning && piIsReady && nextPiCmd != CMD_STOP_SCAN && !singleStepInProgress)
  {
    piIsReady = false;
    if (!readFilmEndPin())
    {
      if (scanExtraFrames == 0)
      {
        scanFilmEndCount++;
        if (scanFilmEndCount >= 3)  // require 3 consecutive film-end reads
        {
          // Film end confirmed - start countdown to scan film remainder
          scanExtraFrames = 25;
          Serial.println(F("Film ended - scanning 25 extra frames"));
        }
      }
    }
    else
    {
      scanFilmEndCount = 0;  // reset counter if film is detected
    }
    
    if (scanExtraFrames > 0)
    {
      scanExtraFrames--;
      if (scanExtraFrames == 0)
      {
        Serial.println(F("Extra frames done - stopping scan, ejecting film"));
        stopScanning();
        filmEjectAdvances = 15;  // start eject phase
        motorFWD1();  // start first eject advance
      }
      else
      {
        motorFWD1();  // advance; CMD_SHOOT_RAW sent by stopMotorISR when film stops
      }
    }
    else
    {
      motorFWD1();  // advance; CMD_SHOOT_RAW sent by stopMotorISR when film stops
    }
  }

  // Handle film eject advances (after scan ends)
  if (filmEjectAdvances > 0 && !singleStepInProgress)
  {
    filmEjectAdvances--;
    if (filmEjectAdvances > 0)
    {
      motorFWD1();  // next eject advance
    }
    else
    {
      Serial.println(F("Film eject complete"));
    }
  }

  // Read the trim pots to determine PWM width for the Motor
  dummyread = analogRead(CONT_RUN_POT);
  fps18MotorPower = map(analogRead(CONT_RUN_POT), 0, 1023, 255, motorMinDuty);
  dummyread = analogRead(SINGLE_STEP_POT);
  singleStepMotorPower = map(analogRead(SINGLE_STEP_POT), 0, 1023, 255, motorMinDuty);

  if (currentButton != prevButton) {
    prevButton = currentButton;
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

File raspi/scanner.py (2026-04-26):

#!/usr/bin/python3
"""Raspi-side Scan Control Glue communicating between Raspi, Arduino and the Raspi HQ Cam"""

from time import sleep
from typing import Optional
import argparse
import enum
import errno
import math
import subprocess
import sys
import signal
import time
import os
import os.path
import shlex
import secrets
import atexit
import threading
from collections import deque
import json
import re
import shutil
import RPi.GPIO as GPIO
import logging

import numpy as np
from PIL import Image, ImageDraw, ImageFont
from smbus2 import SMBus
from picamera2 import Picamera2, Preview
from libcamera import Transform, controls
from datetime import datetime

# basic configuration variables
RAW_DIRS_PATH = "/mnt/ramdisk/" # This is where the camera saves to. Has to end with a slash
FULL_RESOLUTION = (4056, 3840)

SENSOR_BIT_DEPTH = 12
DEBUG_DRAIN = False  # Log frame-drain timing to diagnose out-of-order captures
# Minimum frames to always discard after motor stop regardless of latency setting.
# Edit these to tune the safety floor; they are NOT exposed in the UI.
DRAIN_MIN_DISCARD_4K_FLOOR = 1
DRAIN_MIN_DISCARD_2K_FLOOR = 0
# User-adjustable capture latency: number of frames to discard after motor stop.
# Automatically scales to any framerate (2K ~33 ms/frame, 4K ~100 ms/frame).
CAPTURE_LATENCY_STEPS_FRAMES = [0, 1, 2, 3, 4]
CAPTURE_LATENCY_DEFAULT_IDX = 1  # 1 frame
CAPTURE_LATENCY_FILE = os.path.join(os.path.dirname(__file__), ".capture_latency")

# --- Controller MCU (ATmega328P) Power Switch ---
UC_POWER_GPIO = 16  # GPIO16 (physical pin 36) enables µC power switch on the controller PCB
UC_POWER_BOOT_DELAY_S = 0.5  # allow the ATmega328P to boot before first I2C transaction

# lsyncd config switching
LSYNCD_DIR = "/home/pi/Filmkorn-Raw-Scanner/raspi"
LSYNCD_ACTIVE_CONF = os.path.join(LSYNCD_DIR, "lsyncd.active.conf")
LSYNCD_CONF_NET = os.path.join(LSYNCD_DIR, "lsyncd-to-host.conf")
LSYNCD_CONF_LOCAL = os.path.join(LSYNCD_DIR, "lsyncd-local-hd.conf")

AUTO_SHUTTER_SPEED = 0  # Zero enables AE, used in Preview mode
DISK_SPACE_WAIT_THRESHOLD = 200_000_000  # 200 MB
DISK_SPACE_ABORT_THRESHOLD = 30_000_000  # 30 MB
FPS_AVG_WINDOW = 0  # 0 = all frames in scan, >0 = rolling window size
USB_POWER_CHECK_INTERVAL_S = 30.0
USB3_CHECK_INTERVAL_S = 5.0
MCU_HEX_HASH_CACHE_ENABLED = True  # Enable/disable .mcu_hex_hash caching to skip verification

SHUTTER_SPEED_RANGE = 300, 500_000  # 300µs to 0.5s. This defines the range of the exposure potentiometer
EXPOSURE_VAL_FACTOR = math.log(SHUTTER_SPEED_RANGE[1] / SHUTTER_SPEED_RANGE[0]) / 1024

storage_location = None
current_screen = None
ready_screen_polling = False
camera_running = False
no_camera = False
sensor_size = None
raw_format = "SBGGR12"  # uncompressed 12-bit raw, updated in setup()
overlay_cache = {}
preview_started = False
preview_size = (640, 480)
overlay_ready = False
pending_overlay = None
ready_to_scan = False
last_status_screen = None
shutting_down = False
default_scaler_crop = None
shutdown_timer = None
shutdown_requested_at = None
ramdisk_empty_polling = False
last_fps_value = None
last_shutter_value = None
_last_shoot_raw_end_time: Optional[float] = None
current_resolution_switch = None
last_resolution_label = None
last_sleep_toggle = 0.0
sleep_mode = False
last_sleep_button_state = 1
last_sleep_button_change = 0.0
sleep_button_armed = True
idle_since = None
_scan_idle_since = None  # monotonic timestamp of first consecutive IDLE during active scan
SCAN_IDLE_TIMEOUT = 3.0  # seconds of continuous IDLE during scan before re-sending READY
shutter_speed = AUTO_SHUTTER_SPEED
# Per-frame sensor-clock calibration for transport-frame drain.
# Recorded after each saved frame to anchor SensorTimestamp ↔ monotonic mapping.
_last_frame_sensor_ts = None   # SensorTimestamp (camera clock, nanoseconds)
_last_frame_mono_ts   = None   # time.monotonic() when that capture_request() returned
latency_mode = False
latency_selected_idx = CAPTURE_LATENCY_DEFAULT_IDX  # working selection while in menu
latency_stored_idx = CAPTURE_LATENCY_DEFAULT_IDX    # loaded/saved value used during scanning
overlay_supported = True
overlay_retry_count = 0
overlay_retry_timer = None
last_usb_health_check = 0.0
usb_speed_warning_logged = False
usb_power_warning_logged = False
last_usb_power_check = 0.0
last_usb_speed_check = 0.0
power_warning_active = False
usb3_warning_active = False
dmesg_since = None

# OTA updates: only consider tags that start with this prefix (e.g. "v" for v0.9.2). Use "" to allow any semver tag.
OTA_TAG_PREFIX = "v"

update_mode = False
update_tags = []
update_selected = 0
update_scroll_offset = 0
update_current_tag = None
update_in_progress = False
update_error = None
update_confirmation_mode = False
update_confirmation_selected = 0  # 0 = No, 1 = Yes
pairing_mode = False
pairing_exit_pending = False
logs_mode = False
logs_in_progress = False
unpair_in_progress = False
unpair_mode = False
unpair_confirmation_mode = False
unpair_confirmation_selected = 0  # 0 = No, 1 = Yes
awb_mode = False
awb_selected = 0
awb_scroll_offset = 0
awb_stored_idx = 2  # Cached stored AWB setting (default to Daylight)
AWB_OPTIONS = [
    ("~3600K", controls.AwbModeEnum.Tungsten),
    ("~4500K", controls.AwbModeEnum.Fluorescent),
    ("~5500K", controls.AwbModeEnum.Daylight),
]
AWB_FILE = os.path.join(os.path.dirname(__file__), ".awb_mode")
menu_mode = False
menu_selected = 0
menu_scroll_offset = 0
# Scan target selection
target_mode = False
target_selected = 0
# Language selection
locale_mode = False
locale_selected = 0
target_scroll_offset = 0
target_stored_idx = 2  # Default to GPIO5 (auto mode)
target_validation_error = False  # True when showing validation error screen
target_validation_failures = []  # List of failed tests: "ping", "ssh", "write"
last_target_unknown_command = None  # Track last unknown command to avoid log spam
pending_menu_entry = False  # Flag to enter menu mode after arduino is initialized
TARGET_OPTIONS = [
    ("USB-Drive", 1),      # storage_location = 1
    ("Host Computer", 0),  # storage_location = 0
    ("GPIO5", 2),          # storage_location = read from GPIO5
]
TARGET_FILE = os.path.join(os.path.dirname(__file__), ".scan_target_mode")
# WiFi setup mode
wifi_mode = False
wifi_selected = 0
wifi_scroll_offset = 0
wifi_portal_process = None  # Subprocess running the captive portal
WIFI_NETWORKS_FILE = os.path.join(os.path.dirname(__file__), ".wifi_networks")
MENU_ITEMS = [
    "menu.item.language",
    "menu.item.calibrate-motor",
    "menu.item.capture-latency",
    "menu.item.filmend-sensor",
    "menu.item.preview-wb",
    "menu.item.setup-wifi",
    "menu.item.start-pairing",
    "menu.item.scan-target",
    "menu.item.firmware-update",
    "menu.item.create-debug-log",
    "menu.item.factory-reset",
]
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

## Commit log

2020-07-09 MVP complete, missing all I2C comm stuff though
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2020-10-17 fix lamp mode not being synced with arduino
2020-10-17 fix CMD_LAMP_ON and CMD_LAMP_OFF being switched
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2020-12-19 Fixing deletion of empty raw dirs, adding --continue-at parameter, Fixes occasional duped frames
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2022-03-27 Revert i2c integrity logic
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2022-12-17 Fixed bugs that had probably already been fixed somewhere in the commit tree
    [scan-controller.ino]
2022-12-29 hostname consistency and Readme udpates in progress
    [scan-controller-kicad.kicad_pcb, scan-controller-kicad.kicad_sch]
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2023-10-30 Updating to KiCad 7
    [scan-controller-kicad.kicad_sch]
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2023-10-31 Adding Datasheets, fixing schematics
    [scan-controller-kicad.kicad_sch]
2023-11-01 Lots of schematics fixes. Passes ERC now.
    [scan-controller-kicad.kicad_sch]
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2023-11-08 Bug Fixing switched 3v3 supply
    [scan-controller-kicad.kicad_pcb, scan-controller-kicad.kicad_sch]
2023-11-08 Making the 5V Regulator a subsheet
    [5V_3A_Regulator.kicad_sch, scan-controller-kicad.kicad_sch]
2023-11-08 Moved to Raspi powering our HAT. The ZVD might still make sense though in the 3v3 line, in the case of FTDI or ICSP powering.
    [scan-controller-kicad.kicad_sch, zero_voltage_diode.kicad_sch]
2023-11-10 Adding ZVD to protect the Raspi fro FTDI- or ICSP-Powering
    [ZVD.kicad_sch]
2023-11-10 Making the Sheet Hierarchical for better overview
    [drivers.kicad_sch, scan-controller-kicad.kicad_sch, sensors.kicad_sch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]
2023-11-10 It's getting neat and readable
    [scan-controller-kicad.kicad_sch, userinterface.kicad_sch]
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2023-11-10 Adding missing components Mfnrs and footprints
    [ZVD.kicad_sch, drivers.kicad_sch, scan-controller-kicad.kicad_sch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]
2023-11-10 Adding Constant Current LED Driver
    [drivers.kicad_sch]
2023-11-10 Fixing KSQ GND
    [drivers.kicad_sch]
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2023-11-12 31 nets to go
    [drivers.kicad_sch, scan-controller-kicad.kicad_pcb, scan-controller-kicad.kicad_sch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]
2023-11-12 *Visually* all routed ¯\_(ツ)_/¯
    [scan-controller-kicad.kicad_pcb]
2023-11-16 Backzp before upgrading to Kicad Nightly due to DRC errors
    [scan-controller-kicad.kicad_pcb]
2023-11-16 Pushbutton PTHs now mechanical (DRC fun)
    [drivers.kicad_sch, scan-controller-kicad.kicad_pcb, scan-controller-kicad.kicad_sch]
2023-11-16 Fixes all Footprint DRC Errors
    [scan-controller-kicad.kicad_pcb]
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2023-11-18 Changes shape to hold the cehapo 5.0" Display as cover
    [scan-controller-kicad.kicad_pcb, userinterface.kicad_sch]
2023-11-18 Ripping it ALL apart again
    [scan-controller-kicad.kicad_pcb]
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2023-11-18 Labels, Keep-out, L moved away from camera cable
    [drivers.kicad_sch, scan-controller-kicad.kicad_pcb, sensors.kicad_sch]
2023-11-18 More labels & cleanup
    [scan-controller-kicad.kicad_pcb]
2023-11-19 Looks like we have a Rev. A
    [scan-controller-kicad.kicad_pcb]
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2023-11-19 Saving before Kicad update
    [scan-controller-kicad.kicad_pcb]
2023-11-19 Adding a switch for Storage Target
    [scan-controller-kicad.kicad_pcb, scan-controller-kicad.kicad_sch, userinterface.kicad_sch]
2023-11-19 Fixing BOM
    [drivers.kicad_sch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]
2023-11-19 Orderable Rev.A, with U1 90, Q3 Q7 U5 U9 180° wrong
    [scan-controller-kicad-top-pos.csv]
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2023-11-30 Connect PGIO with SCL (instead of SDA) for power. Connect Atmega SDA to bus (was nc)
    [scan-controller-kicad.kicad_pcb, scan-controller-kicad.kicad_sch]
2023-12-01 Fixing I2C Conns. Power Button still broken
    [scan-controller-kicad.kicad_pcb, scan-controller-kicad.kicad_sch]
2023-12-03 Reduced Power LED Brightness (0.3 mA @ 2.2V, wow), FIxed Power Switch Footprint
    [scan-controller-kicad.kicad_sch, userinterface.kicad_sch]
2023-12-04 Flip U6, it broke the KSQ
    [drivers.kicad_sch, scan-controller-kicad.kicad_pcb, scan-controller-kicad.kicad_sch]
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2023-12-05 Fixing R35 (270 instead of 90k9)
    [drivers.kicad_sch]
2023-12-05 Fixing Shunt Connection to enable Current Control
    [drivers.kicad_sch, scan-controller-kicad.kicad_pcb]
2023-12-17 Addicg .lck to .gitignore, saving before eye refactoring
    [drivers.kicad_sch]
2023-12-17 Add the missing BJP Transistor for the shaft eye
    [scan-controller-kicad.kicad_pcb, scan-controller-kicad.kicad_sch, sensors.kicad_sch]
2023-12-17 Flipping J5/6 to have GND on Pin 1; Invert the Shaft Eye's ISR
    [scan-controller-kicad.kicad_pcb, sensors.kicad_sch]
2023-12-17 Moving Button lables to silkscreen layer
    [scan-controller-kicad.kicad_pcb]
2023-12-17 Freeing up D4 (328) as it isn't needed
    [ZVD.kicad_sch, drivers.kicad_sch, scan-controller-kicad.kicad_pcb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]
2023-12-18 Improved the TP Symbol/Footprint
    [scan-controller-kicad.kicad_pcb, scan-controller-kicad.kicad_sch]
2023-12-18 TPs renamed (using https://forum.kicad.info/t/answer-how-to-avoid-annotate-adding-number-but-still-label-pcb/38283/17)
    [scan-controller-kicad.kicad_pcb, scan-controller-kicad.kicad_sch, sensors.kicad_sch]
2023-12-19 Replacing D6 LED with 1N4148 Adding TPs for Lamp Current Fixing TP Labels and other Labels Add LED D9 that actually reflects Lamp status Add control LEDs for Eyes (makes mounting much easier) Add min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
    [drivers.kicad_sch, scan-controller-kicad.kicad_pcb, scan-controller-kicad.kicad_sch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]
2023-12-19 ERC & DRC happy
    [scan-controller-kicad.kicad_pcb]
2023-12-20 Last Version with the second OpAmp stilll in use
    [drivers.kicad_sch, scan-controller-kicad.kicad_sch]
2023-12-20 Lamp Driver final, but now off grid :-?
    [drivers.kicad_sch, scan-controller-kicad.kicad_pcb]
2023-12-20 Fixing the Lamp Driver Grid
    [drivers.kicad_sch]
2023-12-20 Added Mounting Holes back in
    [drivers.kicad_sch, scan-controller-kicad.kicad_pcb]
2023-12-20 Adding Eye Mounting Holes....
    [scan-controller-kicad.kicad_pcb]
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2023-12-20 Saving before renumbering refs
    [scan-controller-kicad.kicad_pcb, scan-controller-kicad.kicad_sch]
2023-12-20 Hiding some Refs the right way
    [scan-controller-kicad.kicad_pcb, sensors.kicad_sch]
2023-12-20 Fixing TP appearance
    [scan-controller-kicad.kicad_pcb]
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2023-12-21 Updating 3p Terminal Blocks to some available type
    [drivers.kicad_sch, scan-controller-kicad.kicad_pcb, sensors.kicad_sch]
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2023-12-30 KiCad Todos, && do not send exp-value yet
    [scan-controller-kicad.kicad_sch]
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2024-01-03 Fixing bootstrapper's fuse handling
2024-01-04 Do not read the exposure_pot while buttons are pressed
    [scan-controller-kicad.kicad_sch]
2024-01-05 very high hysteresis to reduce the obscure noise :(
    [scan-controller.ino]
2024-01-05 fix the "dead keys" issue
    [scan-controller.ino]
2024-01-05 add dummy reads to the ADC to prevent bleeding
    [scan-controller.ino]
2024-01-06 go a liztle slower to avoid i2c "collisions"
    [scanner.py]
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2024-01-06 Get rid of wireData, finally solving the i2c jamming!
    [scan-controller.ino]
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2024-01-10 fixing fim's crazy cpu load
    [scanner.py]
2024-01-10 procedurize fim, fix wrong screen bug after disk full
    [scanner.py]
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2024-01-12 Switching back to Rev-B (newer Displays have their outputs on the left hand side)
    [scan-controller-kicad.kicad_pcb, scan-controller-kicad.kicad_sch, userinterface.kicad_sch]
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2024-01-12 Looking good, just the new 5VDC source is missing
    [scan-controller-kicad.kicad_pcb, scan-controller-kicad.kicad_sch]
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2024-01-13 Adding a Gate Driver and making the MOSFET tougher. DRC happy!
    [drivers.kicad_sch, scan-controller-kicad.kicad_pcb, scan-controller-kicad.kicad_sch]
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2024-01-15 fixing a missing global declaration
    [scanner.py]
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2024-02-01 Turn off the lamp after Reboot
    [scan-controller.ino]
2024-02-01 Renaming Post-MOSFET TP Motor GND to Lamp GND. Doh!
    [drivers.kicad_sch, scan-controller-kicad.kicad_pcb]
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2024-02-02 Fix Logging Syntax Errors
    [scanner.py]
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2024-02-03 Cosmetic PCB Changes (not in sync with netlist yet)
    [drivers.kicad_sch, scan-controller-kicad.kicad_pcb, scan-controller-kicad.kicad_sch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]
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2024-03-24 Avoiding multiple fims and their zombies
    [scanner.py]
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2025-12-19 KiCad Update to 8.0.8 resaved these files (no changes by me)
    [ZVD.kicad_sch, drivers.kicad_sch, scan-controller-kicad.kicad_pcb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]
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2025-12-20 Detect missing Drive for local storage mode
    [scanner.py]
2025-12-20 avoid flicker when no drive connected
    [scanner.py]
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2025-12-22 improve i2c errorhandling, giving arduino more time to power up
    [scanner.py]
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2025-12-22 Target toggling didnot have an initial state
    [scanner.py]
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2025-12-22 more fixes to gpio17 polling
    [scanner.py]
2025-12-23 Fixing Preview Camera Settings
    [scanner.py]
2025-12-23 set initial (wrong, but consistent) crop factor
    [scanner.py]
2025-12-23 Do not hang for 2 minutes when camera teardown fails
    [scanner.py]
2025-12-23 also catch failing mkdir approaches
    [scanner.py]
2025-12-25 Fix restoring preview when disk space on ramdisk is sufficeint again.
    [scanner.py]
2025-12-27 Fixing initial screen rendition
    [scanner.py]
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2025-12-27 Fix a crah when switching resolution
    [scanner.py]
2025-12-27 shorten blank time during resolution sitching
    [scanner.py]
2025-12-27 Flip the GPIO05 logic so that default (up) is local storage. FIts better on the GPIO cononector with GND being a neighbour pin.
    [scanner.py]
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2025-12-27 avoid GPIO3/I2C contention by using GPIO26 instead
    [scanner.py]
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2025-12-27 yet more i2c comms fix attempts
    [scanner.py]
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2025-12-28 trying to fix wakeup
    [scanner.py]
2025-12-28 i2c retires broke gpio26 reading. doh
    [scanner.py]
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2025-12-28 stop starting a converter process. we no longer need that.
    [scanner.py]
2025-12-28 fix turning the display back on afetr sleep
    [scanner.py]
2025-12-28 small delay to fix status overlays afetr wakeup
    [scanner.py]
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2025-12-28 fixes a race when starting scanning early
    [scanner.py]
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2025-12-28 Hmm, does this prevent double first frames?
    [scanner.py]
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2025-12-28 fix reachability check, but delay warning
    [scanner.py]
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2025-12-29 initial brown out and usb3 detection
    [scanner.py]
2025-12-29 log first dmesg line re brownouts
    [scanner.py]
2025-12-29 allow sleep mode on new warnings (but no auto-sleep after a brown out!)
    [scanner.py]
2025-12-29 re-test for usb3 while error is showing
    [scanner.py]
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2025-12-29 Fix typos in ino, change sleep timeout to 15 min
    [scan-controller.ino, scanner.py]
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2025-12-30 fix a tuple crash
    [scanner.py]
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2026-01-01 fixing a scanner service crash
    [scanner.py]
2026-01-01 Don't get loop stuck after auto-leaving pairing mode
    [scan-controller.ino, scanner.py]
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2026-01-02 trying to fix missing .user_and_host sempahore
    [scanner.py]
2026-01-03 Try to detect missing or outdated hex on the ino
    [scanner.py]
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2026-01-08 missed to init the buttoChoice, so garbage could come in
    [scan-controller.ino]
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2026-01-09 Disable lens-shading correction with scientific profile
    [scanner.py]
2026-01-09 no longer drop frame #1 due to warmup
    [scanner.py]
2026-01-11 fix single step speed
    [scan-controller.ino]
2026-01-11 prevent single step overlapping
    [scan-controller.ino]
2026-01-11 Try to avoid some led flashing during boot
    [scan-controller.ino]
2026-01-11 cache the hex sha256 to avoid redundant acvrdude reads (slows down service start)
    [scanner.py]
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2026-01-13 Threading issues
2026-01-13 fix a numpy crash, remove legacy settings entry, remove threading
    [scan-controller.ino, scanner.py]
2026-01-13 fix leaving WB mode
    [scan-controller.ino, scanner.py]
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2026-01-13 Let Factory Reset delete prefs
    [scanner.py]
2026-01-13 Fix Target Mode Menu Nav
    [scan-controller.ino]
2026-01-13 reset the ino after servce restart
    [scanner.py]
2026-01-13 allow service restarts even during failng io
    [scanner.py]
2026-01-13 Update status screen correctly to ready-to-scan-net once in host mode
    [scanner.py]
2026-01-13 ..and the other direction. also fixes service shtdowns while seeking usb
    [scanner.py]
2026-01-14 restore previous target after connectivity failure
    [scanner.py]
2026-01-14 Fix nnavigation after failed host connectivity check
    [scan-controller.ino, scanner.py]
2026-01-14 Better error handling for cached target prefs
    [scanner.py]
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2026-01-14 Better Help on network failures
    [scanner.py]
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2026-01-18 Dynamic screens 0.8, skip hex caching for now
    [scanner.py]
2026-01-21 fix the version number pos
    [scanner.py]
2026-01-28 make i2c retires a bit faster to not starve the cam pipeline. Revert the 2s sleep threshold
    [scanner.py]
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2026-01-31 fixing menu hangs afetr connect
    [scanner.py]
2026-01-31 fix portal exit, more logging – attempting fix for menu exit
    [scanner.py]
2026-01-31 fixing menu exit, confirming reconnection
    [scan-controller.ino, scanner.py]
2026-01-31 remove wifi settings on factory reset
    [scanner.py]
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2026-02-01 Add C31 to U9 to form another low pass
    [drivers.kicad_sch, sensors.kicad_sch]
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2026-02-01 Rename Target Switch to Resolution, add actual Target Switch
    [scan-controller-kicad.kicad_sch, userinterface.kicad_sch]
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2026-02-01 Remove Pin numbers from mechanical pins, add unplaced U9 units as NC
    [scan-controller-kicad.kicad_pcb, sensors.kicad_sch]
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2026-02-05 Refactored LED Driver: Switch behind the buck, reduce EMV
    [drivers.kicad_sch, sensors.kicad_sch]
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2026-02-05 All better caps, more suitabel LDO for 50-> 5V
    [drivers.kicad_sch, scan-controller-kicad.kicad_pcb, scan-controller-kicad.kicad_sch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]
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2026-02-18 Only start film end detection once some film was inserted for 30 seconds (to avoid a non-registering loop former pull eing misread)
    [scan-controller.ino]
2026-02-18 Fixing this 30s run threshold
    [scan-controller.ino]
2026-02-19 Detect and handle a missingcamera
    [scanner.py]
2026-02-19 Don't crash on camera detection
    [scanner.py]
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2026-02-19 revert the buffer draining to see if its necessary
    [scanner.py]
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2026-02-19 Revert ino changes to restore original timing
    [scan-controller.ino]
2026-02-19 simpler approach to fix long exp times
    [scanner.py]
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2026-02-20 attemptto fix shutter speed display
    [scanner.py]
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2026-02-22 Fetch tags correctly when not in dev mode
    [scanner.py]
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2026-02-28 Attempt to fix a race when the disk runs full and we don't properly stop the engines
    [scan-controller.ino, scanner.py]
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2026-03-01 Detach ISR after stopping to avoid double action
    [scan-controller.ino]
2026-03-01 Drain differently, the cam clock seems to drift
    [scanner.py]
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2026-03-01 attempt to fix timing issues
    [scanner.py]
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2026-03-01 attempt to fix an i2c deadlock
    [scan-controller.ino, scanner.py]
2026-03-01 fixing a double global declaration
    [scanner.py]
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2026-03-02 revert the live logging, ssh is the bottleneck. deal with it.
    [scanner.py]
2026-03-04 improve i2c failue tolerance
    [scanner.py]
2026-03-04 Fix min latency conversion from 2K to 4K mode
    [scanner.py]
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2026-03-05 revert stepping ramp (counterproductive), leave run ramp in
    [scan-controller.ino]
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2026-03-06 fixing a i2c race with eeprom sync
    [scan-controller.ino, scanner.py]
2026-03-06 More races and bug fixes on the eebackup approach...
    [scan-controller.ino, scanner.py]
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2026-03-06 Fix the fuse setting
2026-03-06 more i2c fixes -.-
    [scan-controller.ino]
2026-03-06 Yet more comms fix attempts
    [scanner.py]
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2026-03-06 Fix HTTS override in tag checking even if devkeys are present
    [scanner.py]
2026-03-08 Added a scan-idle watchdog to circumvent i2c jams
    [scanner.py]
2026-03-08 Add Film End Sensor Options "inverted" and "none"
    [scan-controller.ino, scanner.py]
2026-03-08 fix frimware menu exit
    [scanner.py]
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2026-03-12 fixing the fps HUD accuracy. Doh!
    [scanner.py]
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
